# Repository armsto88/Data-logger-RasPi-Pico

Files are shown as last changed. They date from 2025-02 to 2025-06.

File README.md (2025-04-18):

# 🌱 Enviro Logger – Prototype 1

## Overview

The **Enviro Logger** is an environmental data logging system designed to collect and store abiotic data using up to six sensors.  
- **Three** sensors communicate via the **1-Wire** protocol  
- **Three** sensors communicate via the **I2C** bus  

This versatile configuration supports a wide range of environmental monitoring needs.

The system is part of a broader project aimed at **monitoring microclimates within solar farms**. By capturing temperature and humidity data across different strata—**above and below ground**—the project aims to predict the likelihood of various animal groups inhabiting the site, thereby contributing to **biodiversity enhancement** efforts.

---

## 💾 Data Storage & Connectivity

- Data is saved in **CSV format** across **two SD cards** for redundancy and reliability.  
- When **WiFi** is available, the logger uploads data to a **Google Sheets document** for real-time remote monitoring and analysis.  

This remote access minimizes the need to retrieve physical devices—ideal for **long-term field deployments**.

---

## 🔋 Power Management

An **automatic power-off circuit** ensures energy efficiency:

- A **DS3231 Real-Time Clock (RTC)** controls a **P-channel MOSFET switch**  
- The system powers on and off at **predefined intervals**  
- Greatly reduces power consumption for **autonomous operation**

---

## ☀️ Battery & Solar Charging

- Features a **battery management system with solar charging support**
- Ensures **continuous operation** by recharging during daylight hours
- Ideal for **remote and off-grid environments**

This renewable energy setup allows for **long-term deployment with minimal maintenance**.

---

## 🚀 Future Enhancements

Planned improvements for upcoming versions:

- Enhanced wireless communication (e.g. LoRa, LTE)
- Expanded sensor compatibility

---

## 🔧 Build Overview

📄 [Build Overview](Build_Overview.md)

---

## 💰 Cost Breakdown

| Component | Qty | Unit Price (€) | Total (€) |
|---|-----|---|---|
| **Raspberry Pi Pico WH** | 1 | 7.20 | 7.20 |
| **Waveshare Solar Management Module** | 1 | 15.95 | 15.95 |
| **14500 LiPo Battery** | 1 | 6.00 | 6.00 |
| **SD Card Breakout Board** | 2 | 3.00 | 6.00 |
| **DS18B20 Temperature Sensors** | 3 | 2.95 | 8.85 |
| **SHT30 Sensors** | 3 | 6.00 | 18.00 |
| **IRF4905 P-Channel MOSFETs** | 2 | 1.50 | 3.00 |
| **IRFZ44N N-Channel MOSFET** | 1 | 1.50 | 1.50 |
| **Resistors** | | | |
| - 4.7KΩ | 2 | 0.05 | 0.10 |
| - 220KΩ | 1 | 0.05 | 0.05 |
| - 1KΩ | 1 | 0.05 | 0.05 |
| - 2.2KΩ | 1 | 0.05 | 0.05 |
| - 100KΩ | 1 | 0.05 | 0.05 |
| **PCA9546A I2C Multiplexer** | 1 | 11.00 | 11.00 |
| **Adafruit Proto Underplate** | 1 | 6.00 | 6.00 |
| **Waterproof Housing** | 1 | 15.00 | 15.00 |
| **RJ45 Couplers** | 6 | 4.33 | 26.00 |
| **RJ45 Patch Cables** | 6 | 1.50 | 9.00 |
| **USB Couplers** | 1 | 6.00 | 6.00 |
| **🧮 Total Estimated Cost** | | | **141.90** |

---

## 🧪 Testing

🔋 [Battery Test #1 – "Voltage Profile"](Testing/Test_1/Battery_test.md)

---

# 🌿 Enviro Logger – Prototype 2

## 🔌 PCB Schematic & Design

📘 [PCB Overview](PCB/PCB.md)

---

## 🤝 Contributions

_Interested in contributing?_  
Please open an issue or submit a pull request to suggest improvements, report bugs, or share ideas for future development.

---

## 📄 License

(Include your license type here, e.g. MIT, GPLv3, etc.)

---

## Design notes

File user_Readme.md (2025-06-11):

# 🌿  Data Logger – Quick Start Guide

Welcome to your custom-built solar-powered data logger! This guide will walk you through setting up and testing the device.

---

## 🛠 Step 1 – Install Thonny IDE

Download and install **Thonny**, a beginner-friendly Python editor:

- **Windows**: [Download Installer](https://thonny.org)
- **macOS**: [Download Installer](https://thonny.org)

> Thonny includes Python and is perfect for working with MicroPython on Raspberry Pi Pico.

---

## 🔌 Step 2 – Connect the Logger to Your Computer

1. Plug the **micro-USB** end into the **Raspberry Pi Pico** on the logger.
2. Plug the **USB-A** end into your **computer**.
3. Open **Thonny IDE**.

### Setup Thonny to Recognise the Pico:

- Go to `Tools` → `Options…` → **Interpreter**
- Set **Interpreter** to `MicroPython (Raspberry Pi Pico)`
- Set **Port** to:
  - `COMx` (Windows)
  - `/dev/tty.usbmodem...` (macOS)

Click **OK**. You should see a `>>>` prompt in the Shell.

---

## ⏱️ Step 3 – Power On & Set the Logger’s Real-Time Clock (RTC)

### Power On the Device

- The **power switch** is on the **battery module underneath** the unit (not on the PCB).
- You **can’t see** the switch—feel for it near the **bottom-left edge**.
- Slide it to the **right** to turn on.

> 💡 It’s a snug fit—use your pinky finger. (It’s a design flaw 😅)

- A **green LED** on the PCB will light up to confirm it’s powered on.

### Set the Time

1. In Thonny, open `setting_time_ds3231.py` from the file pane.
2. Click the **Run** button (green triangle, top-left).
3. The logger’s clock will sync to your PC's system time.

---

## 🌱 Step 4 – Connect Sensors & Open Main Script

### Connect the Sensors

- Match each **sensor label** to the correct **port label** on the box.
- Plug in all sensors **before running the script**.

> Plugging sensors in later or in the wrong order will mislabel data.

### Open the Main Script

1. In Thonny, open `main.py` from the left-hand file pane.

---
## 🌐 Step 5 – Update WiFi Credentials (Optional Testing)

Scroll to **line 95** in `main.py`. You’ll see:

```python
ssid, password = 'gigacube-0F3C', '5dTQ7HA8242495T8'
```

Replace this with your own WiFi details. For example:

```python
ssid, password = 'YourWiFiName', 'YourWiFiPassword'
```

> 🔒 **Note**: WiFi is only used to send test data to Google Sheets. The logger still saves data to SD cards even if no WiFi is configured.

Be sure to **save the file** before continuing.

---

## 📊 Step 6 – Run the Logger and View Live Test Data

Open the live data sheet in your browser:  
[📄 Google Sheet – Live Data](https://docs.google.com/spreadsheets/d/1Fp3gE0CN5dDJawXwoVpkiC7PFwAjhU7pCCHq3XwCfAo/edit?usp=sharing)

### ▶️ To Run the Logger:

1. With `main.py` open in Thonny, click the **green Run button** (top-left).
2. The logger will:
   - Connect to WiFi 
   - Take a set of sensor readings
   - Upload to the Google Sheet

> ⏱ It will repeat this process **every 30 minutes** until powered off or the battery is depleted.

---

## 📴 Step 7 – Powering Off the Logger

To turn off the device:

- Use the **same switch** on the **battery module** (feel underneath the unit).
- Slide it to the **left** to completely power down the logger.

> ⚠️ **Important:** This cuts **all power**, including **solar charging**.  
> To allow the solar panel to continue charging the battery, leave the device **switched on**, even when not actively logging.

---

## 💡 Tips & Important Notes

### 🔌 Sensor Setup

- Plug all sensors into the **correct ports** **before running `main.py`**.
- The script assumes a specific order—incorrect or delayed connections will result in **mislabelled data** in both the SD card and Google Sheet.

---

### 💾 SD Cards

- The logger includes **two SD cards** for redundancy.
- The SD slots are **a little awkward to access** due to their design.
- With a bit of familiarity, inserting and removing the cards becomes easier.

---

### ☀️ Solar Charging

- The logger is designed for **continuous operation** using solar power.
- It doesn’t require full sun—**cloudy days usually provide a net-positive charge**.
- However, **unobstructed sky access** gives best performance (as tested).
- The solar panel cable can be **easily extended** with standard 2-wire joins if needed.

---

✅ You're all set!

For questions or troubleshooting, feel free to reach out any time.
thomasgarmstrong88@gmail.com

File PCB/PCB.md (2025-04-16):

# PCB Overview

As part of the development of Enviro Logger (Prototype 2), this document outlines the intention to design and build a custom printed circuit board (PCB) that replaces the various breakout board components used in Prototype 1.

Prototype 1 utilised a modular hardware approach using multiple breakout boards to manage power, data storage, sensor input, and communication. While ideal for prototyping and functional testing, this method introduced unnecessary complexity in wiring, increased the size of the unit, and presented durability challenges for long-term, field-based environmental monitoring.

The aim of the PCB design is to consolidate these components into a single, compact, and robust board optimised for real-world deployment. This will improve reliability, simplify assembly, and reduce the chances of connection failure due to vibration, moisture, or prolonged use in outdoor environments.

### Schematic of the PCB design

Schematic of the PCB design

The new PCB will integrate:
- A microcontroller (Raspberry Pi Pico)
- Data storage via 2 × SD card interface
- 1-Wire and I2C sensor support
- RTC-based power scheduling
- Modular ports for external sensor connectivity

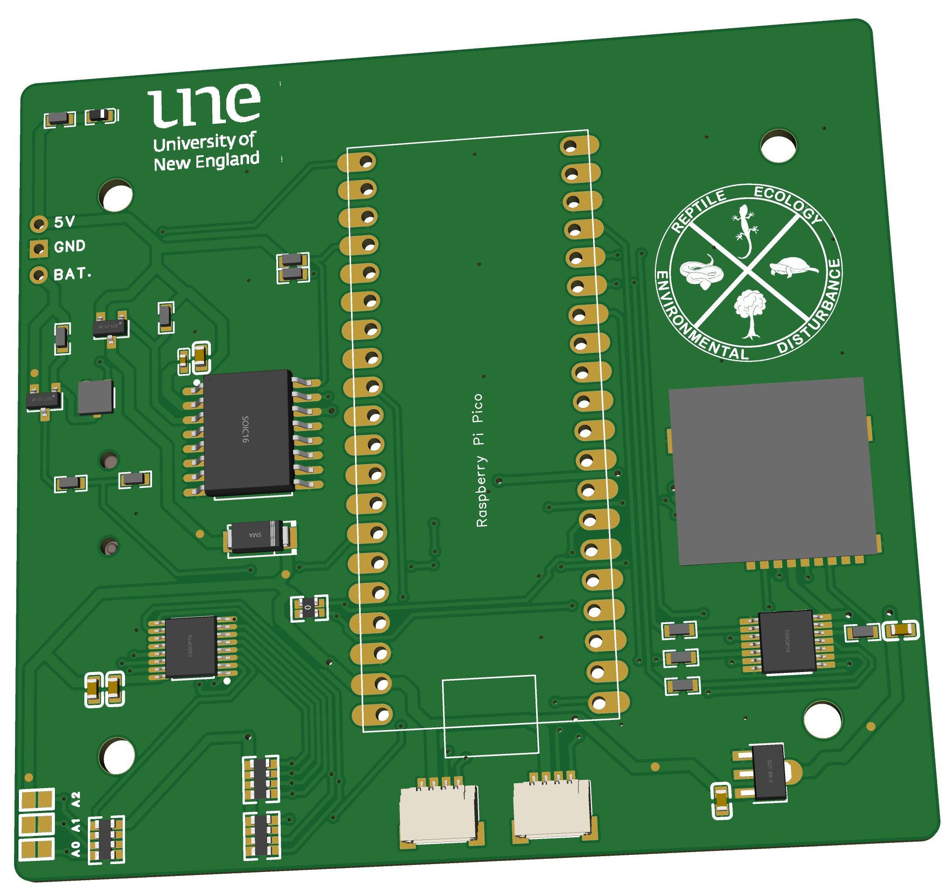
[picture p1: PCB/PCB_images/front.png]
front PCB design

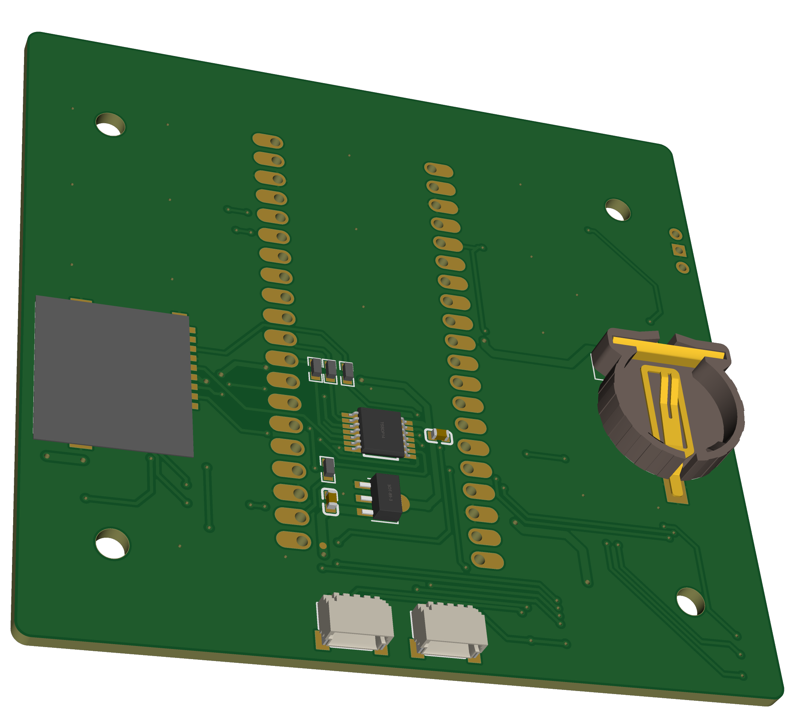
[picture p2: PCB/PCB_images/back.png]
back PCB design


---

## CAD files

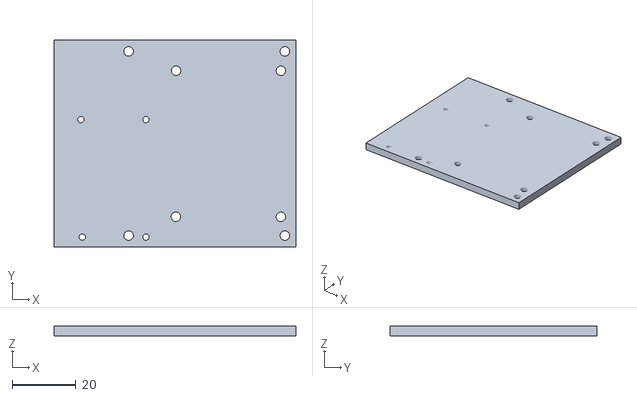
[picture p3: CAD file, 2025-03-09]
3D_prints/top_plate_v21-Body.stl
76.2 x 65.1 x 3.00

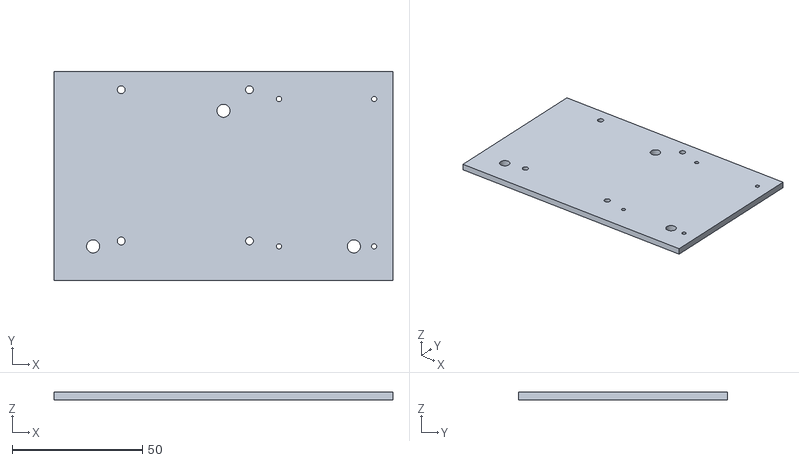
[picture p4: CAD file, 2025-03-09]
3D_prints/base_plate-Body.stl
130.0 x 80.0 x 3.00

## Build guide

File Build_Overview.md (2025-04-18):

# 🛠️ Build Overview

---

This Pico-based Data Logger is a low-power, autonomous environmental monitoring system. It features a Raspberry Pi Pico WH alongside multiple sensors, power management circuits, and data storage components to ensure efficient and reliable data collection. Below is a comprehensive breakdown of the hardware components, followed by step-by-step assembly instructions.

---

## Hardware Components

### 1. Core Processing Unit
- **Raspberry Pi Pico WH** – Handles data acquisition, processing, and storage.

### 2. Sensors
- **Temperature Sensors:**
  - 3 × DS18B20 (1-Wire protocol) for temperature measurements.
- **Temperature & Humidity Sensors:**
  - 3 × SHT30 (I2C protocol) for dual temperature and humidity readings.

### 3. Data Storage
- 2 × SD Card Breakout Boards – Connected via SPI for data storage.

### 4. Power Management
- **Waveshare Solar Power Manager Module** – Manages solar charging and battery output.
- **14500 LiPo Battery** – Provides backup power for continuous operation.
- **DS3231 Real-Time Clock (RTC)** – Controls power cycles to optimize energy consumption.

### 5. Transistors and Resistors
- **MOSFETs:**
  - P-Channel: 2 × IRF4905  
  - N-Channel: 1 × IRFZ44N  
- **Resistors:**
  - 2 × 4.7KΩ  
  - 1 × 220KΩ  
  - 1 × 1KΩ  
  - 1 × 2.2KΩ  
  - 1 × 100KΩ

### 6. Additional Components
- **PCA9546A I2C Multiplexer** – Expands the I2C bus for multiple sensors.
- **Adafruit Proto Underplate** – A prototyping board for mounting and connecting components.
- **Jumper Wires** – For flexible connections.
- **Perf-board** – 6 × 4 cm prototyping board.
- **Waterproof Housing** – [Amazon Link](https://www.amazon.de/-/en/dp/B0D4V6SBXM?ref=ppx_yo2ov_dt_b_fed_asin_title)
- **RJ45 Patch Cables** – [Amazon Link](https://www.amazon.de/-/en/dp/B0797SCT55?ref=ppx_yo2ov_dt_b_fed_asin_title)
- **RJ45 Waterproof Couplings** – [Amazon Link](https://www.amazon.de/-/en/dp/B0CRZ3MTG8?ref=ppx_yo2ov_dt_b_fed_asin_title)

---

## Step-by-Step Assembly

### 1. Setting Up the Raspberry Pi Pico WH

The Raspberry Pi Pico WH comes pre-soldered with headers, making it easier to connect components. However, if you are using a standard **Raspberry Pi Pico** (without pre-soldered headers), you will need to solder them manually before proceeding.

#### Soldering the Headers (If Necessary)

**Required Materials:**
- 40-pin male headers (included with most Pico kits)
- Soldering iron (set to ~350°C or a fixed-temperature iron over 40W)
- Solder
- Breadboard (optional but recommended)

**Steps:**
1. Insert the male headers into a breadboard to hold them steady.
2. Place the Pico board onto the headers with the component side facing up.
3. Heat one corner pin and apply a small amount of solder to hold the header in place.
4. Repeat for the opposite corner to level the board.
5. Solder the remaining pins.
6. Inspect the joints and remove any solder bridges if necessary.

---

### Flashing MicroPython onto the Pico WH using Thonny

Before the Pico WH can run your data logging program, install **MicroPython**.

#### Step 1: Download and Install Thonny
- Visit [Thonny’s official website](https://thonny.org/) and download the appropriate version.
- Install Thonny by following the on-screen instructions.

#### Step 2: Connect the Pico WH in Bootloader Mode
1. Hold down the **BOOTSEL button**.
2. While holding the button, connect the Pico WH to your computer via USB.
3. Release the BOOTSEL button once a drive named **RPI-RP2** appears.

#### Step 3: Install MicroPython
1. Open Thonny.
2. Go to **Run → Select Interpreter**.
3. Select:
   - Interpreter: **MicroPython (Raspberry Pi Pico)**
   - Port: The one where the Pico is connected.
4. If prompted, click **Install** to install MicroPython firmware.

#### Step 4: Test the Installation
In the Python shell (REPL) at the bottom of Thonny, type:

#### **Step 4: Verify MicroPython Installation**
1. After installation, a **Python shell (REPL)** will appear at the bottom of Thonny.
2. Type:
   ```python
   print("Hello, Pico!")
   ```  
   and press **Enter**. If the message prints successfully, MicroPython is installed correctly.

---

### **2. Modifications to the DS3231**

Articles I have read, including this [blog](https://thecavepearlproject.org/2014/05/21/using-a-cheap-3-ds3231-rtc-at24c32-eeprom-from-ebay/), highlight the need for modifications to the DS3231 to ensure proper functionality when using its alarm as a trigger for the P-channel MOSFET.

The DS3231 includes pull-up resistors on the SQW (alarm) line, which must be removed. However, these resistors are part of a resistor block that also contains the necessary I2C lines (SCL, SDA). To compensate for their removal, external 4.7KΩ pull-up resistors must be reintroduced into the circuit to maintain proper operation. This modification provides greater control over the pull-up resistance for the SQW (alarm) line, ensuring reliable triggering.

The other necessary modification is the removal of the charging circuit for the coin battery. The same [blog](https://thecavepearlproject.org/2014/05/21/using-a-cheap-3-ds3231-rtc-at24c32-eeprom-from-ebay/) mentioned earlier, along with other sources, recommends disabling this feature for safety reasons.

To achieve this, the charging resistor can be removed.

The image below highlights both resistors that should be removed. Applying heat and gentle pressure will quickly dislodge them. However, be careful not to apply excessive force, as this could damage the DS3231 or cause injury.

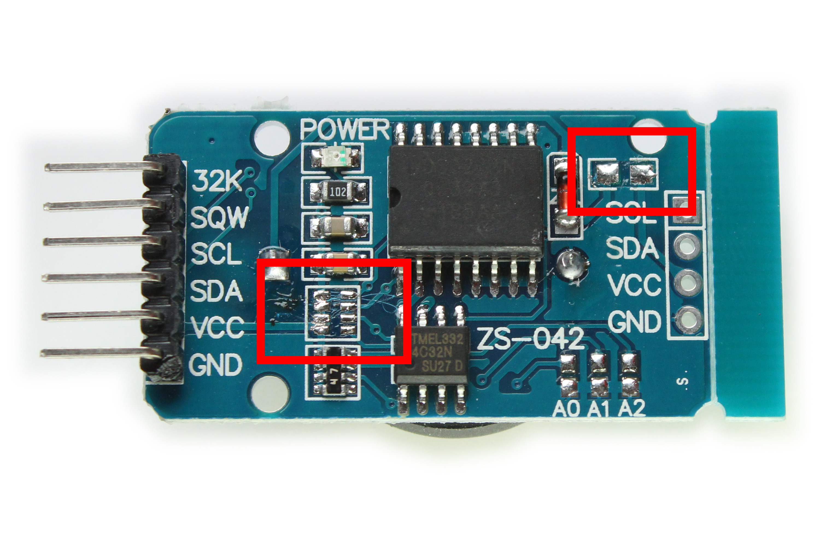
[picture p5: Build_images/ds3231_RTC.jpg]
DS3231 Modifications


---

### **3. Making the Auto-Power Off and Voltage Indicator Circuits**

The auto power-off and voltage measurement circuit was built on a 6 × 4 cm section of double-sided perfboard. Before transitioning to the more permanent perfboard, the circuit was first assembled and tested on a breadboard.

All soldering was done on the underside at a temperature of 350 °C. The resistors used in the voltage divider were 1 kΩ and 2.2 kΩ. External pull-ups for the RTC were 4.7 kΩ, while the pull-ups for the transistor in the voltage divider were 100 kΩ, and for the auto power-off, 220 kΩ.

The voltage divider was powered directly from the battery, with leads soldered to the positive and negative terminals. This approach was necessary because the main output of the Waveshare power unit is boosted to 5V.

Below are some images to assist in its reconstruction. I plan to make this into a PCB hat for the Pico in the future.

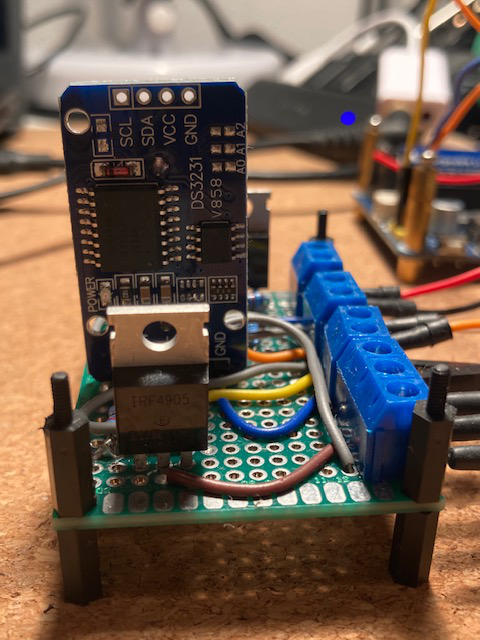
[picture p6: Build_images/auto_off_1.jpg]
Auto-off Circuit 1
  
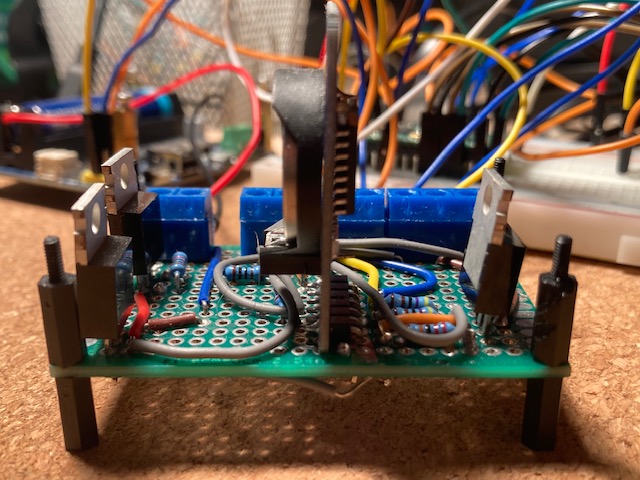
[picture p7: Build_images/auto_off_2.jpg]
Auto-off Circuit 2
  
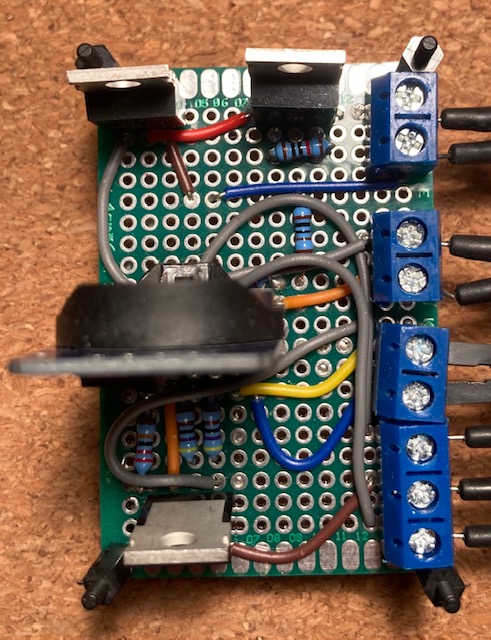
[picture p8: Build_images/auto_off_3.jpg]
Auto-off Circuit 3


---

### **4. Preparing the Waterproof Housing**

I decided to use **RJ45 couplers** ([link](https://www.amazon.de/dp/B0CRZ3MTG8?ref=ppx_yo2ov_dt_b_fed_asin_title&th=1)) to connect the sensors through the waterproof case. This choice was mainly driven by cost. While there are likely more robust and better-form-factor waterproof through couplers available, these were much more affordable at the time.

I drilled **23mm holes** using a **Forstner drill bit** ([link](https://www.amazon.de/-/en/dp/B0BQ7CHXVP?ref=ppx_yo2ov_dt_b_fed_asin_title)) through the bottom of the case. Care must be taken when measuring the holes, as there is little tolerance. I ensured that the long side of the coupler was oriented on the outside of the box to provide more space for cabling later on.

A waterproof gland also needs to be added to the right side of the case for the solar input. I installed this after mounting the hardware and positioning it inside the case to ensure proper placement. I used a [PG7 Waterproof Gland](https://www.amazon.de/-/en/PUWOWYE-PG13-5-Connection-Waterproof-Feed-Through/dp/B0D838PL5S) for this purpose.

---

### **5. Preparing the Sensors**

Using RJ45 couplers required modifying the ends of each sensor to allow them to connect properly. To achieve this, I purchased some short [Cat7 patch cables](https://www.amazon.de/dp/B0797SCT55?ref=ppx_yo2ov_dt_b_fed_asin_title&th=1). I cut a 10 cm length, removed the shielding to expose the four wire pairs, then stripped and twisted the pairs together.

For the temperature sensors, which have three wires, one pair could be discarded. The connector and the sensor wire were then soldered together and insulated. The humidity/temperature sensors, however, use a digital protocol that requires four wires, meaning all pairs from the Cat7 cable are needed.

**Be sure to note where each wire is connected to the RJ45 plug, as you'll need to replicate this inside the box and route each wire correctly to the Pico.**

I chose to merge the three wires from each temperature sensor inside the case before routing them to the Pico. Since they use the digital "1-wire" protocol, this connection needed to be made somewhere, and doing it inside the case kept the wiring clean.

This involved soldering all power wires together, all ground wires together, and all signal wires together using three pairs from another set of RJ45 connectors. Three wires (Power, Ground, and Signal) then emerged from the connectors and were routed to the Pico.

The humidity/temperature sensors, which use the I2C protocol, needed to pass through a multiplexer since they all shared the same digital address. The multiplexer I used had four STEMMA QT connectors as inputs, so I soldered these to the ends of each RJ45 connector inside the box.

The output of the multiplexer (another STEMMA QT) was then routed into the provided input on the proto underplate, reducing cable clutter and avoiding the need for an additional four wires running directly into the Pico's GPIOs.

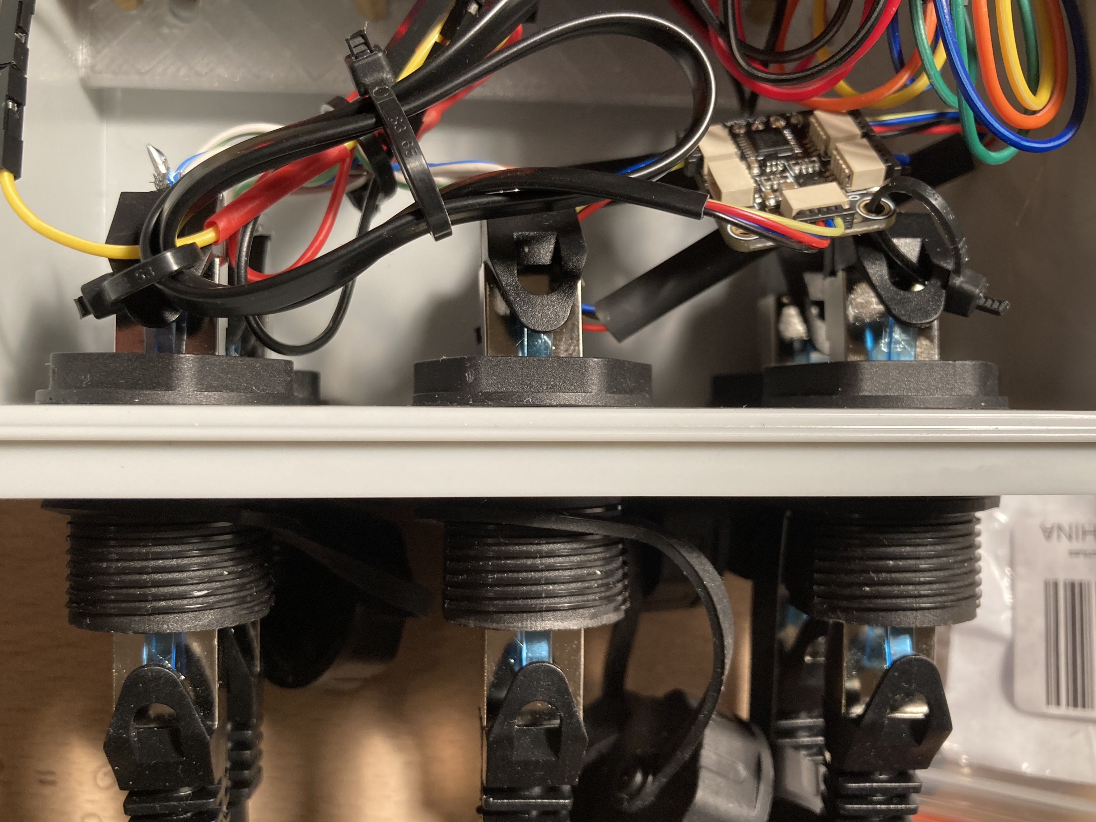
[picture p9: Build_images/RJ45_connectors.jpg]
Connectors


---

### **6. Connecting the Hardware**

My plan was to design a plate that sits atop the Waveshare power manager, providing a mounting surface for both SD card readers and the proto underplate with the Pico on top. The auto power-off circuit is mounted directly onto a backing plate that spans the width of the case.

Files for printing both mounting plates can be found in the repository:

- **[Base plate](3D_prints/base_plate-Body.stl)**
- **[Small mounting plate](3D_prints/top_plate_v21-Body.stl)**

*Note: The prints may require some re-drilling and adjustments to align the holes properly.*

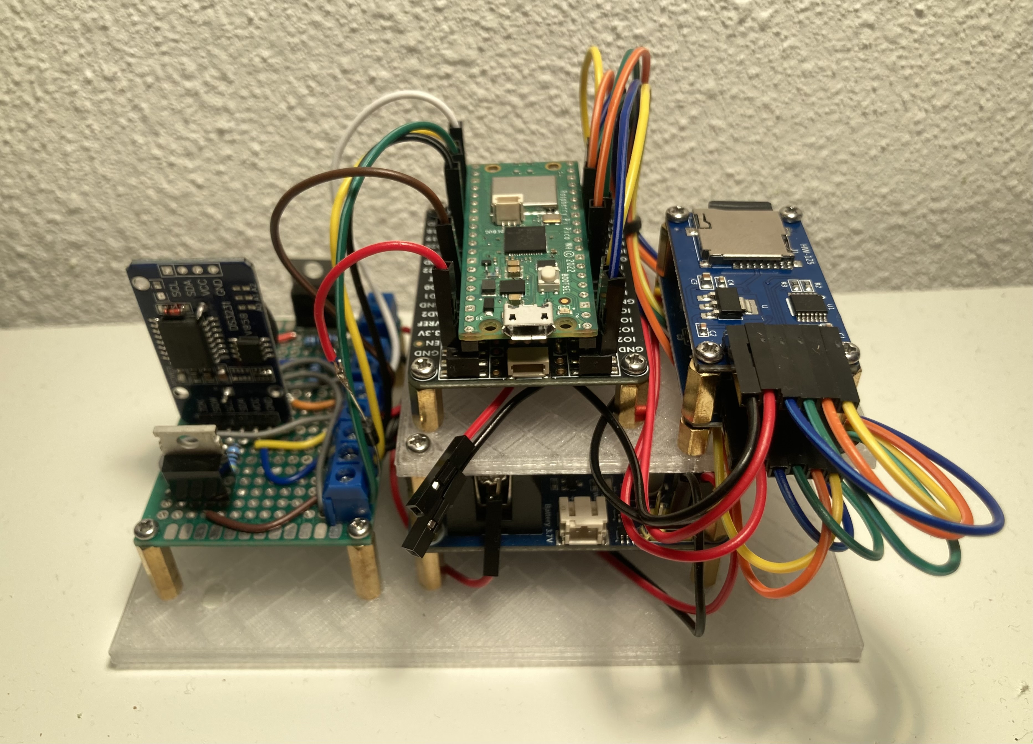
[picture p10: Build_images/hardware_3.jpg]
Hardware Mounting


---

### **7. Bringing It All Together**

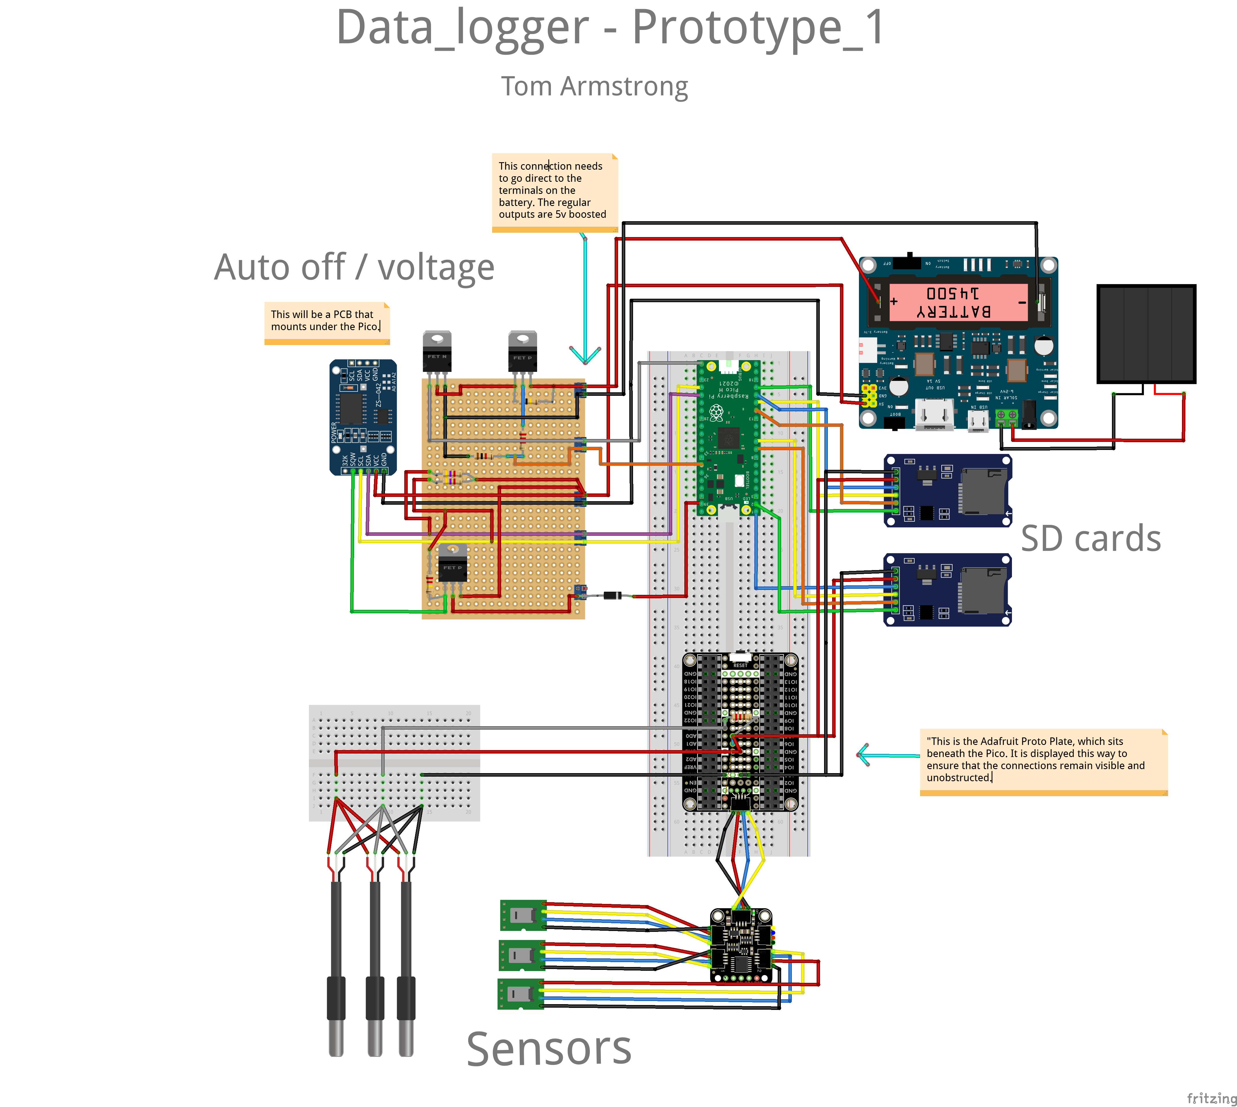
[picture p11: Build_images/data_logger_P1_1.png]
Breadboard View
  
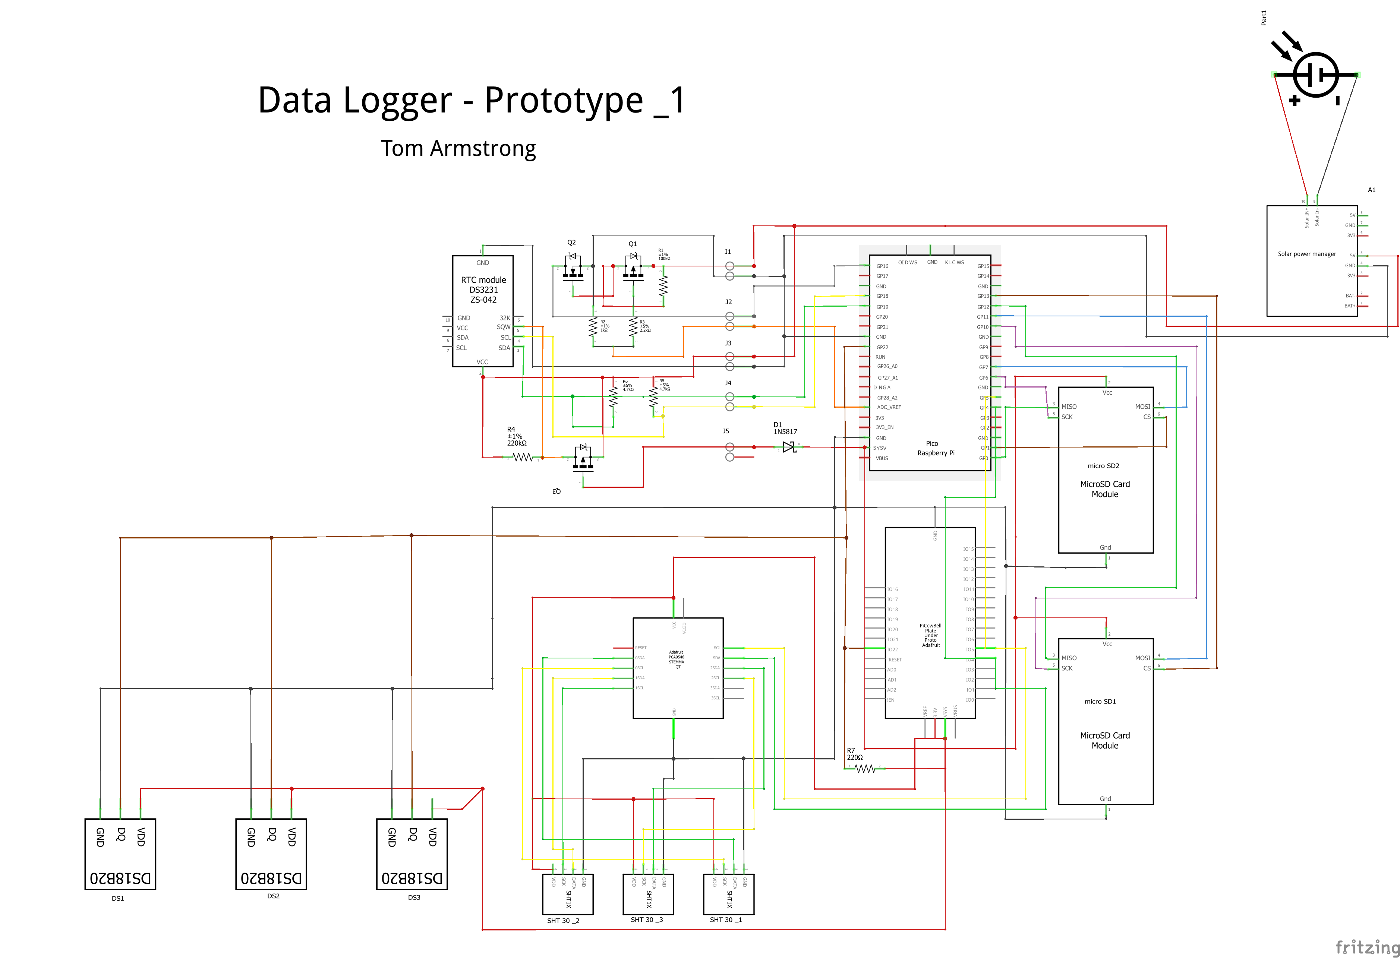
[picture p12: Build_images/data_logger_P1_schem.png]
Schematic View


---

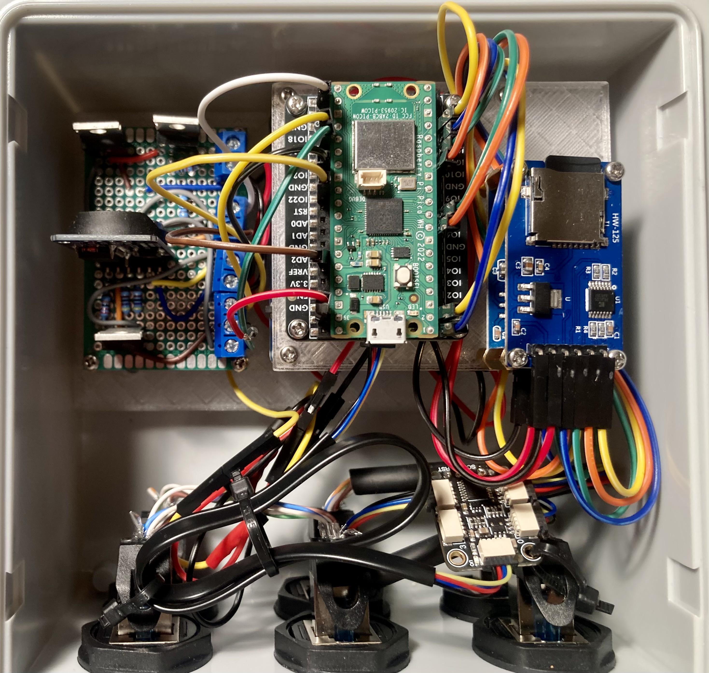
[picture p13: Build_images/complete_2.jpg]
Final Build


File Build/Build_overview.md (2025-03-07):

# Build Overview

----

This Pico-based Data Logger is a low-power, autonomous environmental monitoring system. It incorporates a Raspberry Pi Pico WH, multiple sensors, power management circuits, and data storage components to ensure efficient and reliable data collection. Below is a comprehensive breakdown of the hardware components, along with step-by-step assembly instructions.

## Hardware Components

1. Core Processing Unit

    Raspberry Pi Pico WH – Microcontroller handling data acquisition, processing, and storage.

2. Sensors

    Temperature Sensors:
        3 × DS18B20 (1-Wire protocol) for temperature measurements.
    Temperature & Humidity Sensors:
        3 × SHT30 (I2C protocol) for dual temperature and humidity readings.

3. Data Storage

    2 × SD Card Breakout Boards – Connected via SPI for data storage.

4. Power Management

    Waveshare Solar Power Manager Module – Manages solar charging and battery output.
    14500 LiPo Battery – Provides backup power for continuous operation.
    DS3231 Real-Time Clock (RTC) – Controls power cycles to optimize energy consumption.

5. Transistors and Resistors

    MOSFETs:
        P-Channel: 2 × IRF4905
        N-Channel: 1 × IRFZ44N
    Resistors:
        2 × 4.7KΩ
        1 × 220KΩ
        1 × 1KΩ
        1 × 2.2KΩ
        1 × 100KΩ

6. Additional Components

    PCA9546A I2C Multiplexer – Used to expand the I2C bus for multiple sensors.
    Adafruit Proto Underplate – A prototyping board for mounting and connecting components.
    Jumper wires
    Perf-board (i used 6 x 4 cm)
    Water proof housing ( https://www.amazon.de/-/en/dp/B0D4V6SBXM?ref=ppx_yo2ov_dt_b_fed_asin_title )
    RJ45 patch cables (https://www.amazon.de/-/en/dp/B0797SCT55?ref=ppx_yo2ov_dt_b_fed_asin_title)
    RJ45 water proof couplings (https://www.amazon.de/-/en/dp/B0CRZ3MTG8?ref=ppx_yo2ov_dt_b_fed_asin_title)

  ## **Step-by-Step Assembly**  

### **1. Setting Up the Raspberry Pi Pico WH**  

The Raspberry Pi Pico WH comes pre-soldered with headers, making it easier to connect components. However, if you are using a standard **Raspberry Pi Pico** (without pre-soldered headers), you will need to solder them manually before proceeding.  

### **Soldering the Headers (If Necessary)**  
If you are using a **Raspberry Pi Pico (non-WH version)** without pre-soldered headers, follow these steps:  

#### **Required Materials:**  
- **40-pin male headers** (included with most Pico kits)  
- **Soldering iron** (set to ~350°C)  (or a a fixed temperatrure iron over 40W)
- **Solder**  
- **Breadboard** (optional but recommended)  

#### **Steps:**  
1. Insert the **male headers** into a breadboard to hold them steady.  
2. Place the **Pico board** onto the headers with the component side facing up.  
3. Heat one **corner pin** with the soldering iron and apply **a small amount of solder** to hold the header in place.  
4. Repeat for the opposite corner to keep the board level.  
5. Solder the remaining pins, ensuring a clean, shiny connection without excess solder.  
6. Inspect the joints and remove any solder bridges if necessary.  

### **Flashing MicroPython onto the Pico WH using Thonny**  

Before the Pico WH can run your data logging program, you must install **MicroPython**—a lightweight Python implementation designed for microcontrollers. Follow these steps to flash MicroPython onto your Pico WH using **Thonny IDE**:  

#### **Step 1: Download and Install Thonny**  
1. Visit [Thonny’s official website](https://thonny.org/) and download the version suitable for your operating system.  
2. Install Thonny by following the on-screen instructions.  

#### **Step 2: Connect the Pico WH in Bootloader Mode**  
1. **Hold down the BOOTSEL button** on the Pico WH.  
2. While holding the button, **connect the Pico WH to your computer** using a micro-USB cable.  
3. Release the **BOOTSEL button** once the device appears as a new storage drive named **RPI-RP2** on your computer.  

#### **Step 3: Download and Install MicroPython**  
1. Open **Thonny IDE**.  
2. Click on **"Run" → "Select Interpreter"** from the menu.  
3. In the dialog box, choose:  
   - **Interpreter**: MicroPython (Raspberry Pi Pico)  
   - **Port**: Select the COM port where the Pico is connected  
4. If MicroPython is not already installed, Thonny will prompt you to **install MicroPython firmware**.  
5. Click **"Install"** and wait for the process to complete.  

#### **Step 4: Verify MicroPython Installation**  
1. After installation, a **Python shell (REPL)** will appear at the bottom of Thonny.  
2. Type:  
   ```python
   print("Hello, Pico!")
   ```  
   and press **Enter**. If the message prints successfully, MicroPython is installed correctly.  

---

### **2. Modifications to the DS3231**

Articles I have read, including this [blog](https://thecavepearlproject.org/2014/05/21/using-a-cheap-3-ds3231-rtc-at24c32-eeprom-from-ebay/), highlight the need for modifications to the DS3231 to ensure proper functionality when using its alarm as a trigger for the P-channel MOSFET.  

The DS3231 includes pull-up resistors on the SQW (alarm) line, which must be removed. However, these resistors are part of a resistor block that also contains the necessary I2C lines (SCL, SDA). To compensate for their removal, external 4.7KΩ pull-up resistors must be reintroduced into the circuit to maintain proper operation. This modification provides greater control over the pull-up resistance for the SQW (alarm) line, ensuring reliable triggering.

The other necessary modification is the removal of the charging circuit for the coin battery. The same [blog](https://thecavepearlproject.org/2014/05/21/using-a-cheap-3-ds3231-rtc-at24c32-eeprom-from-ebay/) mentioned earlier, along with other sources, recommends disabling this feature for safety reasons.  

To achieve this, the charging resistor can be removed.  

The image below highlights both resistors that should be removed. Applying heat and gentle pressure will quickly dislodge them. However, be careful not to apply excessive force, as this could damage the DS3231 or cause injury.



### **3. Making the auto-power off and voltage indicator circuits**

The auto power-off and voltage measurement circuit was built on a 6 × 4 cm section of double-sided perfboard. Before transitioning to the more permanent perfboard, the circuit was first assembled and tested on a breadboard.

All soldering was done on the underside at a temperature of 350 °C. The resistors used in the voltage divider were 1 kΩ and 2.2 kΩ. External pull-ups for the RTC were 4.7 kΩ, while the pull-ups for the transistor in the voltage divider were 100 kΩ, and for the auto power-off, 220 kΩ.

The voltage divider was powered directly from the battery, with leads soldered to the positive and negative terminals. This approach was necessary because the main output of the Waveshare power unit is boosted to 5V.

Below are some images to assist in its reconstruction. I plan to make this into a PCB hat for the pico in the future.

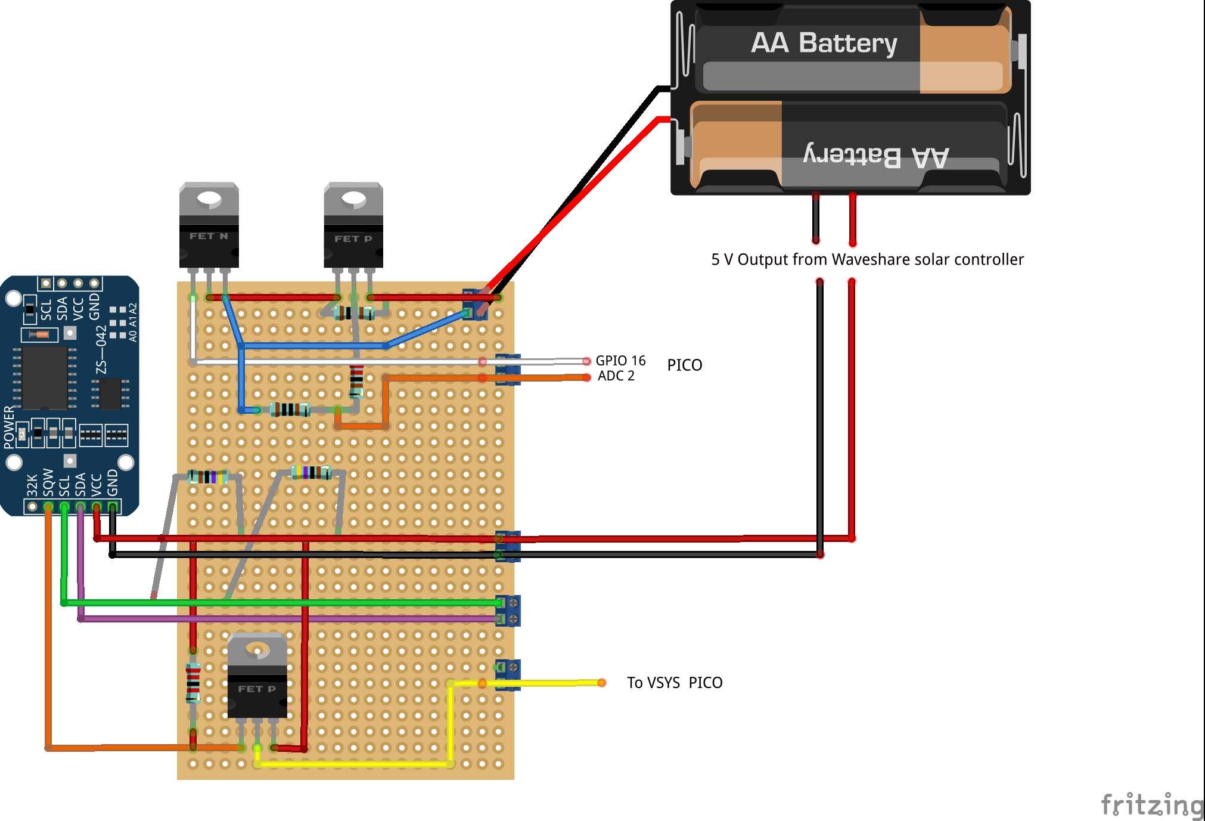
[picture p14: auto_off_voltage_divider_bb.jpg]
Auto-off circuit


Auto-off circuit
Auto-off circuit
Auto-off circuit

### **4. Preparing the water-proof housing**

### **5. Preparing the Sensors.**

### **6. Connecting the hardware.**

### **7. Bringing it all together.**

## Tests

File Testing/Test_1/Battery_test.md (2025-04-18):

# Test 1: Battery Life

### Objective:
The goal of this test was to determine how long the data logger could operate on a fully charged battery under normal operating conditions, as well as to assess its overall power consumption profile.

### Method:

1. **Fully Charged the Battery**:
   - Verified that the battery was completely charged to 100% using the "LED charge status" indicator on the Waveshare power manager unit.
   - Measured the battery's voltage using a multimeter for an initial baseline.

2. **Ran the Data Logger Under Normal Load**:
   - Configured the data logger to record data at the standard sampling rate of 30-minute intervals.
   - Ensured that all sensors were running simultaneously to simulate real-world conditions:
     - 3 x DS18B20 temperature sensors
     - 3 x SHT30 humidity/temperature sensors
   - Used Wi-Fi to transmit data to the cloud during the test.

3. **Monitored Battery Status**:
   - Continuously monitored the battery level throughout the test using the system's battery tracking feature.
   - Logged the battery percentage at regular intervals and tracked its decrease over time.
   - Periodically validated the battery readings by using a multimeter to measure the system's voltage, ensuring accurate voltage measurements.

4. **Test Duration**:
   - Let the system run until the battery voltage reached 3.2V (the lowest safe voltage before potentially damaging the battery).
   - **Test Conditions**: Conducted tests in two different environments:
     - Indoor conditions with relatively stable temperature (~15°C)
     - Outdoor conditions under typical operating conditions in Germany (March 8th, 2025)

5. **Recorded Findings**:
   - **Documented Conditions**: Recorded temperature and humidity data from the sensors.
     - **Indoor or Outdoor**: Noted the treatment type (Indoor/Outdoor).
     - **Time**: Used datetime stamps of data logs to calculate battery runtime.
     - **Unit Voltage**: Recorded the voltage from the voltage divider on the unit.
     - **Actual Voltage**: Measured voltage periodically with a multimeter at the same time as it was being read by the unit.

6. **Post-Test Analysis**:
   - **Evaluated Performance**: Compared the battery life across both test conditions and noted any temperature variances.
   - **Identified Efficiency Improvements**: Analyzed components that may have consumed more power than anticipated (e.g., sensors, Wi-Fi module, or data storage).

### Results

### 1. **Overview of Test Setup**
   - **Data Logger Configuration**: The data logger was set to record data at 30-minute intervals, using 3 x DS18B20 temperature sensors and 3 x SHT30 humidity/temperature sensors. Data was transmitted to the cloud via Wi-Fi.
   - **Test Conditions**: Two testing environments were used:
     - **Indoor**: Stable temperature (~15°C)
     - **Outdoor**: Normal operating conditions in Germany (March 8th, 2025)
   - **Battery Monitoring**: Battery voltage read from the voltage divider was monitored , with periodic validation using a multimeter.

### 2. **Battery Runtime**

#### **Indoor Test Duration**
- **Start Voltage**: 3.92 V (actual: 3.96 V)  
- **End Voltage**: 3.00 V (actual: 3.00 V)  
- **Total Runtime**: 71.2 hours  

#### **Key Observations**
- The internal voltage reading is approximately **0.02 V lower** than the multimeter reading at its maximum value.  
- Significant noise is present, likely due to the **ADC on the Raspberry Pi Pico**, causing fluctuations of around **±0.2 V**.  
- While the general trend of the internal voltage reading is accurate, it **is not reliable** for low-power shutoff decisions.  
- The **Waveshare power manager** automatically cuts power at **3.0 V**.
   
---
   - **Outdoor Test Duration**:
     - **Start Voltage**: 4.0 V 
     - **End Voltage**: 3.0V
     - **Total Runtime**: 63.2 H
       
     - **Key Observations**
     - The  colder average temperatrure reduced run time by approx. 10 hours.

Voltage vs Time Temperature Plot

### 3. **Recharging Process**

   **Starting volatge**: 3.0V
   
**Day 1** - 100% cloud
**Recharging Time**: 0.4 V in 7.5 hours = 0.053 V / H

**Day 2** - 10% cloud
**Recharging Time**: 0.84 V in 9.5 hours = 0.088 V / H
   
   - **Comments**: Happy with recharge effectivness, particularly on day 1 with 100% cloud. 
     
Recharge_time

### 7. **Conclusion**

The battery life tests provided valuable insight into the data logger's real-world power performance and highlighted both strengths and areas for optimization.

- **Runtime Observations**:
  - Indoors, the logger maintained full functionality for over **71 hours**, indicating strong performance under thermally stable conditions.
  - Outdoors, runtime dropped to **63.2 hours**, confirming that **colder ambient temperatures reduce battery efficiency** by approximately **10 hours**, consistent with expectations for Li-ion cells.

- **Voltage Monitoring**:
  - The internal ADC-based voltage readings from the Pico were generally useful for trend analysis but **not sufficiently accurate** for determining low-voltage cutoffs due to **±0.2 V fluctuation**.
  - External multimeter readings confirmed that the **Waveshare power manager reliably cut off at 3.0 V**, protecting the battery from over-discharge.

- **Recharging Insights**:
  - The system recharged effectively even under **100% cloud cover**, gaining **0.4 V over 7.5 hours**.
  - On a mostly clear day (10% cloud), recharge rate improved to **0.088 V/hour**, reaffirming the **suitability of the solar panel and power management system** for off-grid use.

- **General Performance**:
  - The combination of **low-frequency sampling (30 min intervals)** and **hardware-level power control** allowed the unit to perform as intended, with **multi-day operation** feasible between charges.
  - These results confirm the logger is **well-suited for short-term deployments (2.5–3 days)** on battery alone, and **indefinite operation** is possible with moderate solar exposure.

Overall, the test confirms the data logger is capable of sustained autonomous operation under real-world conditions and is suitable for deployment in field-based microclimate studies.

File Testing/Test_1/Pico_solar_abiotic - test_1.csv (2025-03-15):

 | datetime | X | temperature_ds1 | temperature_ds2 | temperature_ds3 | shtc3_temp_1 | shtc3_temp_2 | shtc3_temp_3 | shtc3_hum_1 | shtc3_hum_2 | shtc3_hum_3 | Batt_voltage | X.1 | Acc..V | cumulative_hours
1 | 2025-03-07 09:47:58 | NA | 15.375 | 15.4375 | 15.6875 | 15.65118 | 15.47227 | 15.79805 | 45.243 | 44.99275 | 44.63874 | 3.919762 | NA | 3.96 | 0
2 | 2025-03-07 10:00:16 | NA | 15.4375 | 15.5625 | 15.5625 | 15.65118 | 15.66987 | 16.1078 | 46.21805 | 45.76181 | 45.01106 | 3.932653 | NA | 3.95659515570934 | 0.205
3 | 2025-03-07 11:00:13 | NA | 16.25 | 16.4375 | 16.375 | 16.47097 | 16.50301 | 16.84481 | 49.67422 | 48.99825 | 48.37415 | 3.644294 | NA | 3.94 | 1.20416666666667
4 | 2025-03-07 11:11:19 | NA | 16.9375 | 16.75 | 16.6875 | 16.6659 | 16.6846 | 16.85817 | 49.97635 | 49.14779 | 48.8426 | 3.9432 | NA | 3.93831818181818 | 1.38916666666667
5 | 2025-03-07 11:30:13 | NA | 16.8125 | 17.1875 | 16.9375 | 16.95964 | 16.93828 | 17.02907 | 49.59792 | 49.10658 | 49.06233 | 3.911559 | NA | 3.93545454545455 | 1.70416666666667
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

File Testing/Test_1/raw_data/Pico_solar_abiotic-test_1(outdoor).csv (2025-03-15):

 | Datetime | Temp1 | Temp2 | Temp3 | Humidity1 | Humidity2 | Humidity3 | Batt_voltage | Acc..V | cumulative_hours
1 | 2025-03-12 21:16:00 | 17.06 | 17.19 | 17.13 | 69.82 | 67.49 | 69.19 | 3.88 | 4.02 | 0
2 | 2025-03-12 21:30:00 | 6.19 | 6.5 | 6.38 | 69.59 | 73.9 | 75.26 | 4 | 4.01679389312977 | 0.233333333333333
3 | 2025-03-12 22:00:00 | 4.44 | 4.75 | 4.63 | 82.49 | 84.45 | 85.62 | 3.98 | 4.00992366412214 | 0.733333333333333
4 | 2025-03-12 22:30:00 | 3.63 | 3.94 | 3.88 | 83.56 | 86.2 | 86.79 | 3.97 | 4.0030534351145 | 1.23333333333333
5 | 2025-03-12 23:00:00 | 3.38 | 3.63 | 3.56 | 86.45 | 88.09 | 88.78 | 3.96 | 3.99618320610687 | 1.73333333333333
6 | 2025-03-12 23:30:00 | 3.75 | 3.94 | 3.88 | 87.01 | 88.75 | 89.21 | 3.96 | 3.98931297709924 | 2.23333333333333
7 | 2025-03-13 | 3.81 | 4.06 | 4.13 | 85.39 | 86.18 | 87.34 | 3.95 | 3.9824427480916 | 2.73333333333333
8 | 2025-03-13 00:30:00 | 3.63 | 3.88 | 3.94 | 84.91 | 85.04 | 86.63 | 3.94 | 3.97557251908397 | 3.23333333333333
9 | 2025-03-13 01:00:00 | 3.75 | 4 | 4.06 | 84.38 | 84.88 | 86.21 | 3.94 | 3.96870229007634 | 3.73333333333333
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

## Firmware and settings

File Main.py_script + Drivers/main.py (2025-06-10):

import network
import urequests
from machine import Pin, I2C, SoftI2C, ADC, SPI
import time
import sdcard
import uos
import onewire
import ds18x20
import json
from ds3231 import DS3231, EVERY_MINUTE, EVERY_HOUR
import gc
import SHT30
import sys

# Constants
WEBHOOK_URL = "https://hook.eu1.make.com/cxyhxctngdmc1ohme35cxln7fi9s7rjm"
TCA9548A_ADDRESS = 0x71  # TCA9548A I2C address for channel selection
AT_COMMAND_DELAY = 5
R1, R2 = 1000, 2200  # Voltage divider constants

# -------------------- Error Logging Functions --------------------

def get_timestamp():
    """Return a formatted timestamp using the RTC if available, else system time."""
    try:
        _time = rtc.get_time()  # using RTC
        year, month, day, hour, minute, second, _, _ = _time
        return f"{year:04d}-{month:02d}-{day:02d} {hour:02d}:{minute:02d}:{second:02d}"
    except Exception:
        return time.strftime("%Y-%m-%d %H:%M:%S")

def log_error_to_flash(error_message, log_file="/error.log"):
    """Append an error message with a timestamp to a log file on onboard flash."""
    timestamp = get_timestamp()
    try:
        with open(log_file, "a") as f:
            f.write(f"{timestamp} - {error_message}\n")
    except Exception as e:
        # If logging fails, print to the console as a last resort.
        print("Failed to write to onboard error log:", e)
        print(f"{timestamp} - {error_message}")

def log_exception_to_flash(e, context="", log_file="/error.log"):
    """Log an exception along with its context to the onboard error log."""
    timestamp = get_timestamp()
    try:
        with open(log_file, "a") as f:
            f.write(f"{timestamp} - Exception in {context}: {e}\n")
    except Exception as log_e:
        print("Failed to write exception to onboard error log:", log_e)
        print(f"{timestamp} - Exception in {context}: {e}")

# -------------------- Hardware Initialization --------------------

# Basic hardware: LED, MOSFET gate, and ADC.
try:
    led = Pin("LED", Pin.OUT)
    mosfet_gate = Pin(16, Pin.OUT)
    adc = ADC(2)
except Exception as e:
    print(f"Error initializing basic hardware components: {e}")
    log_exception_to_flash(e, "Basic hardware init")

hardware_initialized = True

# I2C, RTC, and SHT30 initialization.
try:
    i2c_1 = SoftI2C(scl=Pin(18), sda=Pin(19))
    rtc = DS3231(i2c_1)
    i2c = I2C(0, sda=Pin(4), scl=Pin(5))
    sht = SHT30.SHT30(i2c)
except Exception as e:
    print(f"Error initializing I2C/RTC/SHT30: {e}")
    log_exception_to_flash(e, "I2C/RTC/SHT30 init")
    hardware_initialized = False

# DS18B20 sensor initialization.
try:
    ds_pin = Pin(22)
    ds_sensor = ds18x20.DS18X20(onewire.OneWire(ds_pin))
except Exception as e:
    print(f"Error initializing DS18B20 sensor: {e}")
    log_exception_to_flash(e, "DS18B20 init")
    ds_sensor = None

gc.collect()

# -------------------- Utility Functions --------------------

def connect_to_wifi():
    """Attempt to connect to WiFi and return the WLAN interface."""
    try:
        wlan = network.WLAN(network.STA_IF)
        wlan.active(True)
        ssid, password = 'gigacube-0F3C', '5dTQ7HA8242495T8'
        
        if not wlan.isconnected():
            wlan.connect(ssid, password)
            start_time, timeout = time.time(), 20
            while not wlan.isconnected() and time.time() - start_time < timeout:
                print(f"Attempting WiFi... {int(time.time() - start_time)}s elapsed")
                time.sleep(2)
        
        if wlan.isconnected():
            print("Connected to WiFi:", wlan.ifconfig())
        else:
            print("Failed to connect to WiFi. Offline mode enabled.")
        gc.collect()
        return wlan
    except Exception as e:
        print(f"WiFi Connection Error: {e}")
        log_exception_to_flash(e, "WiFi Connection")
        return None



def initialize_sd_card(sd_mount="/sd1", cs_pin_num=13, spi_id=1, sck_pin_num=10, mosi_pin_num=11, miso_pin_num=12):
    """Attempt to initialize an SD card and mount it at the specified mount point."""
    cs = Pin(cs_pin_num, Pin.OUT)
    baudrate = 400_000 if sd_mount == "/sd2" else 1_000_000
    spi = SPI(spi_id, baudrate=baudrate, polarity=0, phase=0, bits=8,
              firstbit=SPI.MSB, sck=Pin(sck_pin_num),
              mosi=Pin(mosi_pin_num), miso=Pin(miso_pin_num))

    try:
        uos.umount(sd_mount)
        print(f"Unmounted previous SD card on {sd_mount} (if any).")
    except Exception as e:
        if hasattr(e, 'args') and e.args and e.args[0] == 22:
            print(f"Ignoring unmount error on {sd_mount}: {e}")
        else:
            print(f"Error unmounting SD card at {sd_mount}: {e}")
            log_exception_to_flash(e, f"Unmounting SD card at {sd_mount}")

    try:
        if sd_mount == "/sd2":
            print("Toggling CS pin for /sd2 to stabilise SD card...")
            cs.value(1)
            time.sleep(0.1)
            cs.value(0)
            time.sleep(0.1)
            cs.value(1)
            time.sleep(0.1)

        sd = sdcard.SDCard(spi, cs)
        vfs = uos.VfsFat(sd)
        uos.mount(vfs, sd_mount)
        print(f"SD card initialized and mounted at {sd_mount}.")
        gc.collect()
    except Exception as e:
        print(f"Error initializing SD card at {sd_mount}: {e}")
        log_exception_to_flash(e, f"Initializing SD card at {sd_mount}")
        return None
    return sd


def initialize_first_sd_card():
    """Initialize the first SD card with retry logic."""
    for attempt in range(3):
        print(f"Attempt {attempt + 1} to initialize /sd1...")
        card = initialize_sd_card(sd_mount="/sd1", cs_pin_num=13, spi_id=1,
                                  sck_pin_num=10, mosi_pin_num=11, miso_pin_num=12)
        if card:
            return card
        time.sleep(1)
    print("Failed to initialize /sd1 after 3 attempts.")
    return None


def initialize_second_sd_card():
    """Initialize the second SD card with retry logic."""
    for attempt in range(3):
        print(f"Attempt {attempt + 1} to initialize /sd2...")
        card = initialize_sd_card(sd_mount="/sd2", cs_pin_num=1, spi_id=0,
                                  sck_pin_num=6, mosi_pin_num=7, miso_pin_num=0)
        if card:
            return card
        time.sleep(1)
    print("Failed to initialize /sd2 after 3 attempts.")
    return None

def select_channel(i2c, channel):
    """Select a specific channel on the TCA9548A multiplexer."""
    if 0 <= channel <= 7:
        try:
            i2c.writeto(TCA9548A_ADDRESS, bytearray([1 << channel]))
            print(f"Selected channel {channel}")
        except Exception as e:
            print(f"Error selecting channel {channel}: {e}")
            log_exception_to_flash(e, f"select_channel {channel}")
    else:
        raise ValueError("Invalid channel. Must be between 0 and 7.")

def read_temperature_and_humidity(sensor):
    """Read temperature and humidity from the SHT30 sensor."""
    try:
        temperature, humidity = sensor.measure()
        if temperature is None or humidity is None:
            raise ValueError("Invalid sensor readings")
        return temperature, humidity
    except Exception as e:
        print(f"Error reading SHT30 sensor: {e}")
        log_exception_to_flash(e, "read_temperature_and_humidity")
        return None, None

def log_temperature_to_sd(data_to_log, sd_directory):
    """Append temperature and voltage data as CSV to a log file on the SD card."""
    log_path = f"{sd_directory}/log.csv"
    retries = 3

    try:
        files_in_directory = uos.listdir(sd_directory)
        print(f"Files in directory {sd_directory}: {files_in_directory}")
    except OSError as e:
        print(f"Error reading directory {sd_directory}: {e}")
        log_exception_to_flash(e, f"listdir {sd_directory}")
        return



    # Create the log file with a header if it does not exist.
    if 'log.csv' not in files_in_directory:
        print(f"{log_path} not found. Creating new file.")
        try:
            with open(log_path, 'w') as file:
                file.write(
                    'Datetime,DS18B20_1 Temp,DS18B20_2 Temp,DS18B20_3 Temp,'
                    'SHT30_Channel_1 Temp,SHT30_Channel_1 Hum,'
                    'SHT30_Channel_2 Temp,SHT30_Channel_2 Hum,'
                    'SHT30_Channel_3 Temp,SHT30_Channel_3 Hum,Voltage\n'
                )
        except OSError as e:
            print(f"Error creating file {log_path}: {e}")
            log_exception_to_flash(e, f"create file {log_path}")
            return

    # Try to append the log entry.
    for attempt in range(retries):
        try:
            print(f"Appending to {log_path} (Attempt {attempt + 1}/{retries})")
            with open(log_path, 'a') as file:
                log_values = [
                    data_to_log.get('datetime', 'N/A'),
                    f"{data_to_log.get('temperature_ds1', 0):.2f}",
                    f"{data_to_log.get('temperature_ds2', 0):.2f}",
                    f"{data_to_log.get('temperature_ds3', 0):.2f}",
                    f"{data_to_log.get('shtc3_temp_1', 0):.2f}",
                    f"{data_to_log.get('shtc3_hum_1', 0):.2f}",
                    f"{data_to_log.get('shtc3_temp_2', 0):.2f}",
                    f"{data_to_log.get('shtc3_hum_2', 0):.2f}",
                    f"{data_to_log.get('shtc3_temp_3', 0):.2f}",
                    f"{data_to_log.get('shtc3_hum_3', 0):.2f}",
                    f"{data_to_log.get('voltage', 0):.2f}"
                ]
                log_entry = ",".join(log_values) + "\n"
                file.write(log_entry)
                file.flush()
            print(f"Data logged successfully to {log_path}.")
            return
        except OSError as e:
            print(f"Error writing to {log_path}: {e} (Attempt {attempt + 1}/{retries})")
            log_exception_to_flash(e, f"writing to {log_path}")
            time.sleep(0.5)
    print(f"Failed to write to {log_path} after {retries} attempts.")

def send_data_to_webhook(data_to_send):
    """Send data to the webhook endpoint."""
    try:
        headers = {'Content-Type': 'application/json'}
        response = urequests.post(WEBHOOK_URL, json=data_to_send, headers=headers, timeout=30)
        print("Webhook response:", response.status_code, response.text)
    except Exception as e:
        print("Error sending data to webhook:", e)
        log_exception_to_flash(e, "send_data_to_webhook")

def read_battery_voltage():
    """Read battery voltage using an ADC and the voltage divider."""
    try:
        raw_value = adc.read_u16()
        voltage_out = (raw_value / 65535.0) * 3.3
        vin = voltage_out * ((R1 + R2) / R2)
        return vin
    except Exception as e:
        print(f"Error reading battery voltage: {e}")
        log_exception_to_flash(e, "read_battery_voltage")
        return None

def disconnect_wifi():
    """Disconnect WiFi to conserve power after data upload."""
    wlan = network.WLAN(network.STA_IF)
    if wlan.isconnected():
        wlan.disconnect()
        print("WiFi disconnected.")
    else:
        print("WiFi was not connected.")

# -------------------- Main Logging Routine --------------------

def main():
    gc.collect()

    # Connect to WiFi
    wlan = connect_to_wifi()
    time.sleep(2)

    # Initialize SD cards
    initialize_first_sd_card()
    time.sleep(1)
    initialize_second_sd_card()
    time.sleep(1)

    # Set RTC alarms once on boot (can stay here)
    try:
        print("Setting RTC alarms for every 30 minutes...")
        rtc.alarm1.set(EVERY_HOUR, min=0, sec=0)
        rtc.alarm2.set(EVERY_HOUR, min=30)
    except Exception as e:
        print(f"Error setting RTC alarms: {e}")
        log_exception_to_flash(e, "Setting RTC alarms")

    # Main data logging loop
    while True:
        try:
            time.sleep(1)
            led.value(1)
            print("Collecting data...")

            # Power sensors and measure voltage
            mosfet_gate.value(1)
            time.sleep(2)
            vin = read_battery_voltage()
            if vin is not None:
                print("Voltage: {:.2f} V".format(vin))
            else:
                print("Voltage reading failed.")
            time.sleep(1)
            mosfet_gate.value(0)
            print("MOSFET OFF")

            # RTC datetime
            try:
                _time = rtc.get_time()
                year, month, day, hour, minute, second, _, _ = _time
                datetime_str = f"{day:02d}-{month:02d}-{year:04d} {hour:02d}:{minute:02d}:{second:02d}"
                print("Current datetime:", datetime_str)
            except Exception as e:
                print(f"Error parsing RTC datetime: {e}")
                log_exception_to_flash(e, "RTC datetime parsing")
                datetime_str = "N/A"

            # DS18B20
            ds_temperatures = {}
            if ds_sensor:
                try:
                    ds_sensor.convert_temp()
                    time.sleep_ms(750)
                    sensor_roms = ds_sensor.scan()
                    if sensor_roms:
                        for idx, rom in enumerate(sensor_roms):
                            ds_temperatures[f'Sensor {idx + 1}'] = ds_sensor.read_temp(rom)
                    else:
                        print("No DS18B20 sensors found.")
                except Exception as e:
                    print(f"Error reading DS18B20 sensors: {e}")
                    log_exception_to_flash(e, "DS18B20 reading")
            else:
                print("DS18B20 sensor not initialized.")

            time.sleep(1)

            # SHT30 sensors
            shtc3_data = {}
            for channel in range(3):
                select_channel(i2c, channel)
                temperature, humidity = read_temperature_and_humidity(sht)
                shtc3_data[f'shtc3_temp_{channel + 1}'] = temperature if temperature is not None else 0.0
                shtc3_data[f'shtc3_hum_{channel + 1}'] = humidity if humidity is not None else 0.0

            # Prepare payload
            data = {
                "datetime": datetime_str,
                "temperature_ds1": ds_temperatures.get('Sensor 1', 0.0),
                "temperature_ds2": ds_temperatures.get('Sensor 2', 0.0),
                "temperature_ds3": ds_temperatures.get('Sensor 3', 0.0),
                "shtc3_temp_1": shtc3_data.get('shtc3_temp_1', 0.0),
                "shtc3_hum_1": shtc3_data.get('shtc3_hum_1', 0.0),
                "shtc3_temp_2": shtc3_data.get('shtc3_temp_2', 0.0),
                "shtc3_hum_2": shtc3_data.get('shtc3_hum_2', 0.0),
                "shtc3_temp_3": shtc3_data.get('shtc3_temp_3', 0.0),
                "shtc3_hum_3": shtc3_data.get('shtc3_hum_3', 0.0),
                "voltage": vin if vin is not None else 0.0
            }

            # Save and send data
            log_temperature_to_sd(data, "/sd1")
            time.sleep(1)
            log_temperature_to_sd(data, "/sd2")
            time.sleep(1)

            if wlan and wlan.isconnected():
                send_data_to_webhook(data)
            else:
                print("No WiFi connection, skipping data upload.")

            disconnect_wifi()
            time.sleep(1)
            

            # Clear the alarms (this powers off the system)
            print("Clearing alarms and powering off...")
            rtc.alarm1.clear()
            rtc.alarm2.clear()
            print("Both alarms cleared, system powering off...")

            break
        except Exception as e:
           print(f"Error during shutdown sequence: {e}")
           log_exception_to_flash(e, "Shutdown sequence")
           break

if __name__ == "__main__":
    main()

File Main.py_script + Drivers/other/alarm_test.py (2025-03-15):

import machine
from machine import Pin, SoftI2C
import time
from ds3231 import DS3231, EVERY_MINUTE

# Initialize onboard LED
led = machine.Pin("LED", machine.Pin.OUT)

# Initialize I2C for DS3231
i2c = SoftI2C(scl=Pin(21), sda=Pin(20))

# Initialize DS3231
try:
    rtc = DS3231(i2c)
    print("DS3231 successfully initialized!")
except Exception as e:
    print("Error: DS3231 not found! Check wiring. Exception:", e)
    while True:
        pass  # Stop execution if RTC is not found

# Set DS3231 alarm to trigger at second 0 of every minute
rtc.alarm1.set(EVERY_MINUTE, sec=0)
print("Alarm set to trigger at second 0 of each minute.")

# Add a startup delay to give Pico more time to initialize
print("Starting up... Giving Pico more time to initialize.")
time.sleep(5)  # Adjust this delay to the desired startup time

while True:
    rtc.alarm1.clear()  # Clear any old alarms

    print("Waiting for DS3231 alarm trigger...")
    while not rtc.alarm1():  # Wait for alarm
        time.sleep(0.5)

    print("⏰ Alarm Triggered! Turning ON LED...")
    led.value(1)

    # Keep LED on for 1 second
    time.sleep(20)
    
    rtc.alarm1.clear()  # Reset alarm

    print("Waiting another 30 seconds for manual trigger...")
    time.sleep(10)  # Manually add a second trigger at 30s

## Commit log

2025-03-07 Create Battery Test.md
2025-03-07 Rename Battery Test.md to Battery_test.md
2025-03-07 Rename code/main_script/main.py to Main.py_script + Drivers/main.py
2025-03-10 Update and rename Pico_solar_abiotic - test_1.csv to raw_test_data/Pico_solar_abiotic - test_1.csv
    [Pico_solar_abiotic - test_1.csv]
2025-03-10 voltage over time - test 1
2025-03-15 Update and rename Pico_solar_abiotic-test_1(outdoor).csv to raw_test_data/Pico_solar_abiotic-test_1(outdoor).csv
    [Pico_solar_abiotic-test_1(outdoor).csv]
2025-03-15 Update and rename Pico_solar_abiotic - test_1.csv to Pico_solar_abiotic - test_1_(indoor).csv
    [Pico_solar_abiotic - test_1_(indoor).csv]
2025-03-15 Update and rename Pico_solar_abiotic - test_1.csv to Testing/Test_1/raw_data/Pico_solar_abiotic - test_1.csv
    [Pico_solar_abiotic - test_1.csv]
2025-03-15 Update and rename Testing/Test_1/raw_data/Pico_solar_abiotic - test_1.csv to Testing/Test_1/Pico_solar_abiotic - test_1.csv
    [Pico_solar_abiotic - test_1.csv]
2025-03-15 Update and rename Pico_solar_abiotic-test_1(outdoor).csv to Testing/Test_1/Pico_solar_abiotic-test_1(outdoor).csv
    [Pico_solar_abiotic-test_1(outdoor).csv]
2025-03-15 Update and rename Testing/Test_1/Pico_solar_abiotic - test_1.csv to Testing/Test_1/raw_data/Pico_solar_abiotic - test_1.csv
    [Pico_solar_abiotic - test_1.csv]
2025-03-15 Update and rename Testing/Test_1/Pico_solar_abiotic-test_1(outdoor).csv to Testing/Test_1/raw_data/Pico_solar_abiotic-test_1(outdoor).csv
    [Pico_solar_abiotic-test_1(outdoor).csv]
2025-03-17 Update and rename Raw_data_test_2.csv to recharge_time.csv
    [recharge_time.csv]
2025-04-16 Update and rename PCB/SCH_Pico_Logger_1-RTC_Power off_2025-04-16.svg to PCB/PCB_images/schematic.svg
